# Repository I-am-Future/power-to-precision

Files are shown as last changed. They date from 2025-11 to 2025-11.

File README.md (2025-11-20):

# Open Source Fingertip Resources for "Power to Precision" Project

[Project Webiste](https://jianglongye.com/power-to-precision/) | [arXiv](https://arxiv.org/abs/2511.13710) | [X (Summary)](https://x.com/jianglong_ye/status/1990540705035624817) | [X (Hardware)](https://x.com/laiiwei/status/1991581235567816910)

Boost your dexterous hand’s manipulation ability — almost for free.

This repo offers fully open-source, 3D-printable fingertip *design geometry* and *control sequences* that instantly enhance fine-manipulation skills, enabling your dexterous hand to handle smaller and more delicate objects.

We currently support two hands — [**XHand**](https://www.robotera.com/en/goods1/4.html) and [**Inspire Hand**](https://en.inspire-robots.com/product/rh56dfx).
More hand models will be added, and the optimization scripts will also be released in future updates.

## Asset Links

| Hand Name | Thumb geometry | Index geometry | Control Sequence |
| --- | --- | --- | --- |
| [**XHand**](https://www.robotera.com/en/goods1/4.html) |  [thumb.stl](assets/xhand/thumb.stl) | [index.stl](assets/xhand/index.stl) | [control_seq.json](assets/xhand/control_seq.json) |
| [**Inspire Hand**](https://en.inspire-robots.com/product/rh56dfx) | [thumb.stl](assets/inspire_hand/thumb.stl) | [index.stl](assets/inspire_hand/index.stl) | |
| | | | |

## Prerequisites

1. 3D printer, with PLA or TPU (preferred) filament
2. Electrical insulation tape (e.g., [link](https://a.co/d/dLanJT1) or an equivalent one)
3. Scissors
4. **[Optional]** 3M anti-slip tape (e.g., [link](https://a.co/d/gBPgOIn) or an equivalent one)

## Procedure

We use *XHand* and *Bambu studio* as an example.

### a) 3D Printing

1. Import the `.stl` file into the 3D printing software:

<p align="center">
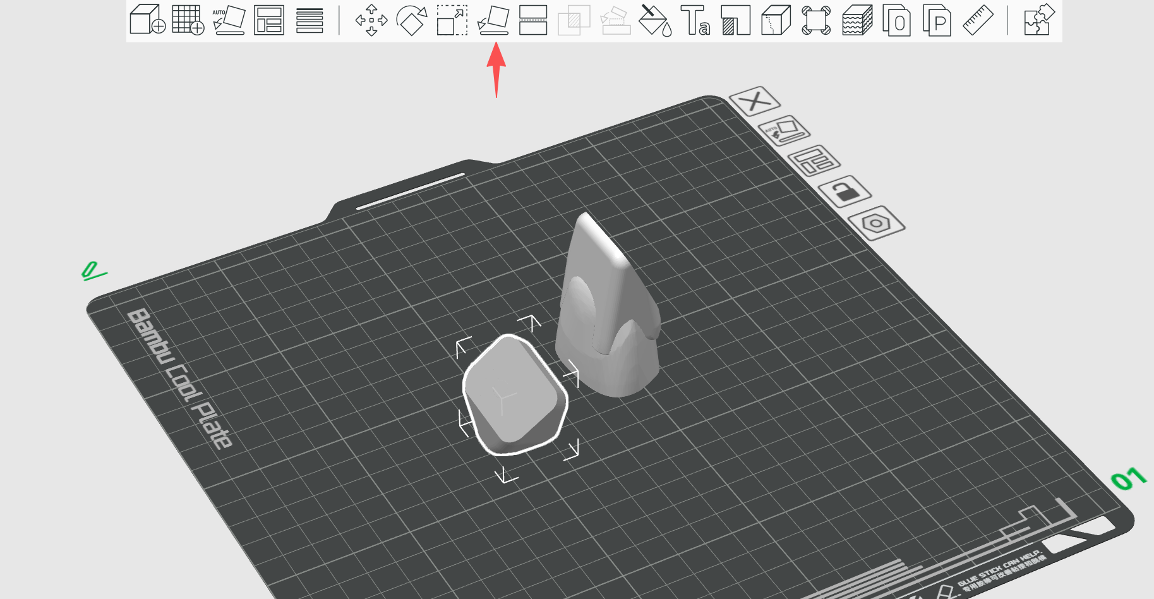
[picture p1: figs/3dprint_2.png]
  
</p>

2. It is recommended to lay the model on this direction, which helps printing. (In bambu studio, you can use this button (red arrow) to reselect the bottom faces)

<p align="center">
  
</p>

3. Finally, enable the printing support on the left panel, and slice the plate. If everything goes fine, print it!

### b) Assembly

1. Use scissors to remove the excess 3D-printed support structures from the printed fingertip.
2. **[Optional]** Apply 3M anti-slip tape to the contact surface of the fingertip.

<p align="center">
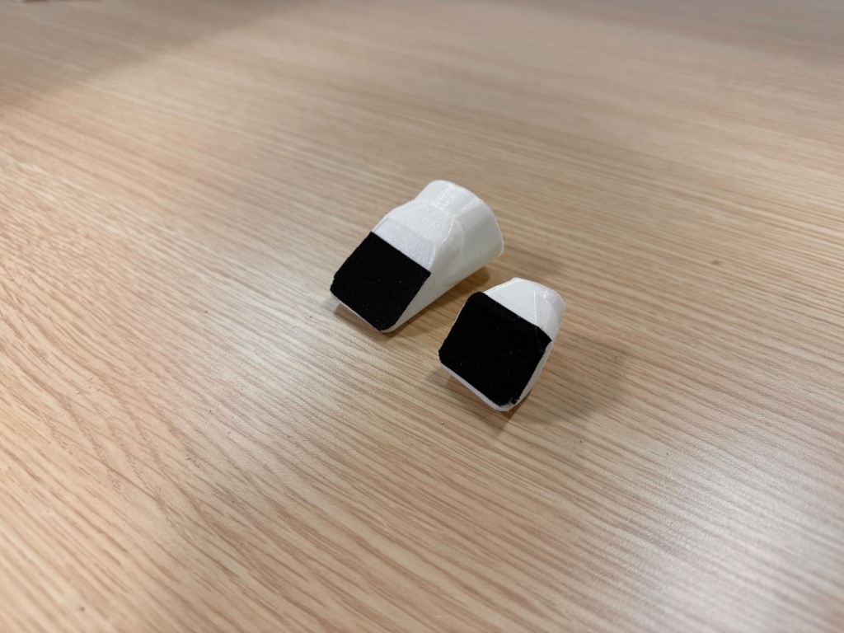
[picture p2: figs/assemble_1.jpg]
  
</p>

3. Gently insert the fingertip onto the robot hand’s finger. Note that the friction may be high—avoid applying excessive force. Slowly wiggle the fingertip left and right while pushing until it is fully seated.

<p align="center">
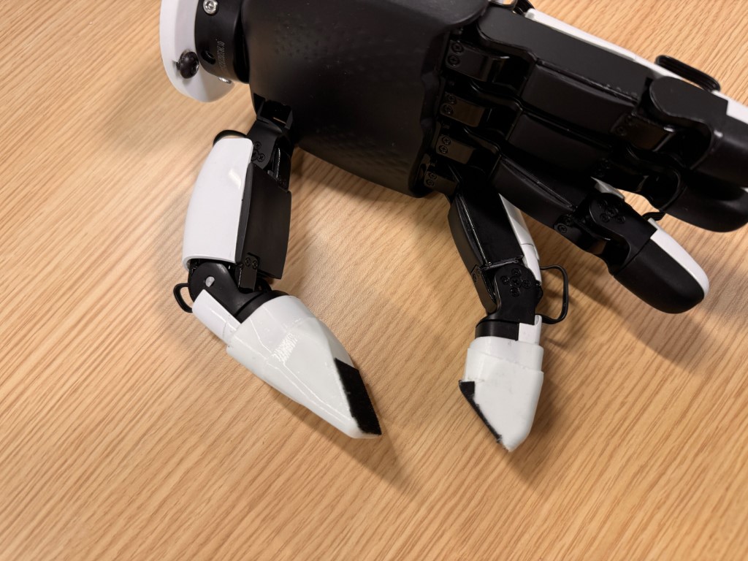
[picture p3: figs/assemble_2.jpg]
  
</p>

4. Cut a ~10 cm piece of electrical tape, stretch it slightly, and wrap it around the joint between the fingertip and the finger.

<p align="center">
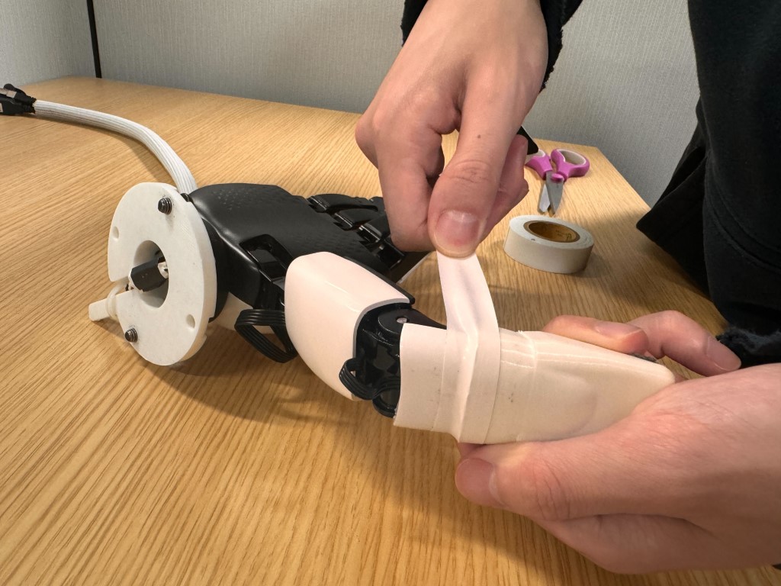
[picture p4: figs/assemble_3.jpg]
  
</p>
5. Finally it looks like this:

<p align="center">
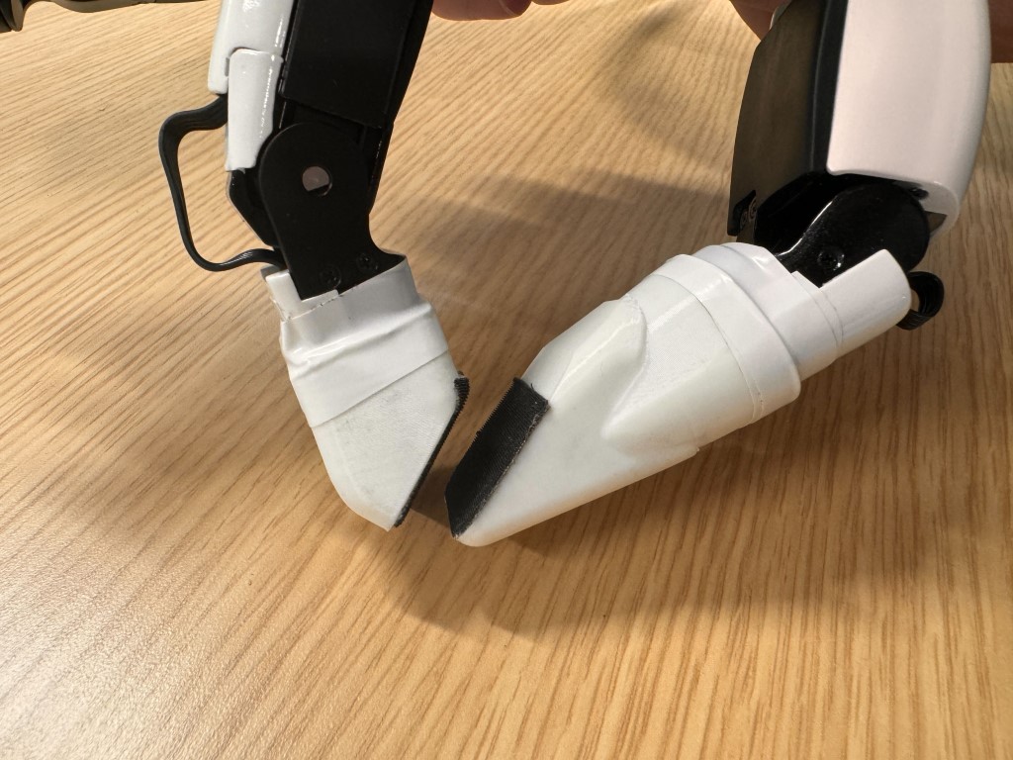
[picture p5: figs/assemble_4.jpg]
  
</p>

### c) Testing

We use *XHand*'s API to test the hand. Install them according to official docs. We'll control xhand by the script `examples/example_xhand.py`. Run by:

```bash
# apart from the XHand's SDK, install necessary packages:
# pip install numpy pynput
python examples/example_xhand.py
```

After starting the script, you can press keyboard `z` and `x` to make fingers open/close.

<p align="center">
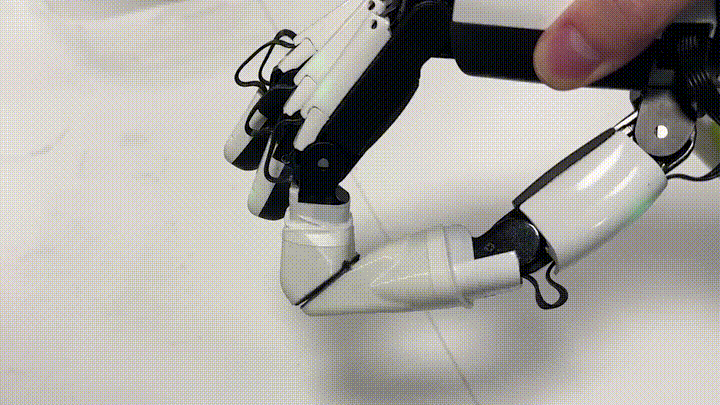
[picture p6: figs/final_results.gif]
  
</p>
<mark><b>! important: calibration</b></mark>

Since each real hand's calibration differs to each other, the provided control sequence may not be the best when deploying to your real hand. You may minorly adjust the control sequence to let it pinch better on your real hand based on the observation. In the `examples/example_xhand.py`, you can adjust it in line 88 of the file.

<mark><b>! important: high contact between fingers</b></mark>

Excessive contact between the thumb and index finger may damage the motors. Please limit the closing angle to ensure that, in the fully closed state, neither motor applies excessive force.

## License & Citation

The assets from this repo are distributed under MIT license.

If you found our project helpful, please cite our paper:

```bibtex
@misc{ye2025powerprecisionlearningfinegrained,
      title={From Power to Precision: Learning Fine-grained Dexterity for Multi-fingered Robotic Hands}, 
      author={Jianglong Ye and Lai Wei and Guangqi Jiang and Changwei Jing and Xueyan Zou and Xiaolong Wang},
      year={2025},
      eprint={2511.13710},
      archivePrefix={arXiv},
      primaryClass={cs.RO},
      url={https://arxiv.org/abs/2511.13710}, 
}
```

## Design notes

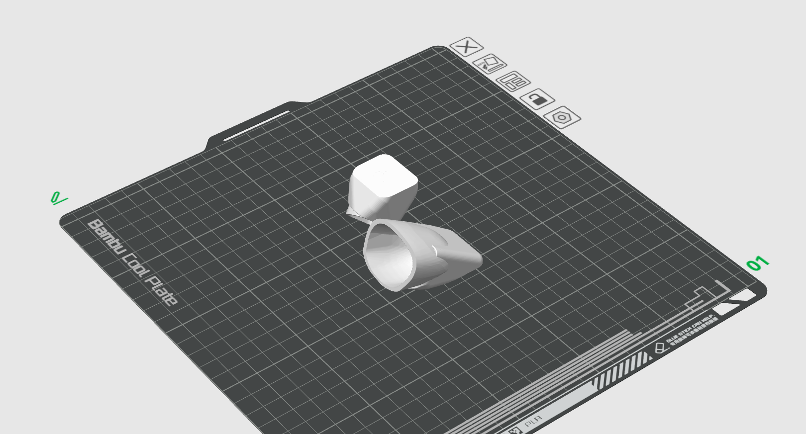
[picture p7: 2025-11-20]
figs/3dprint_1.png

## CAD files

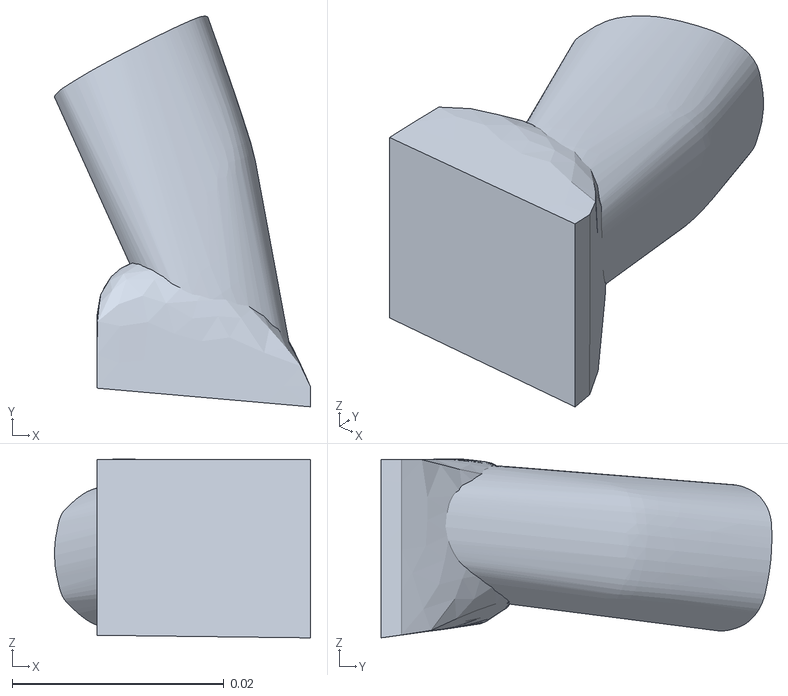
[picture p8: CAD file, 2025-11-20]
assets/inspire_hand/index.stl
0.0242 x 0.0369 x 0.0169

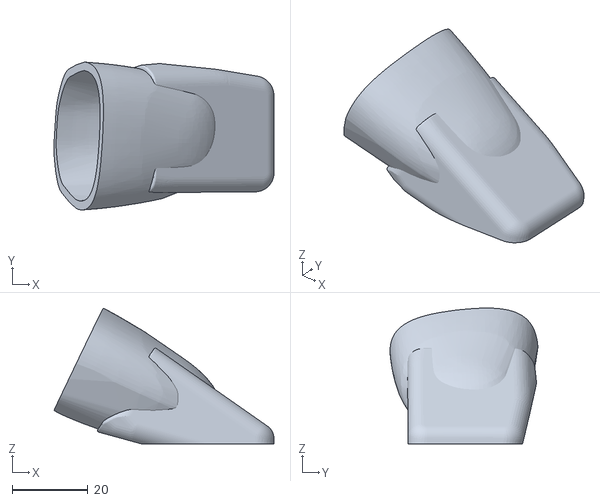
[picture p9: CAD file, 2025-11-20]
assets/xhand/thumb.stl
57.9 x 38.9 x 35.8

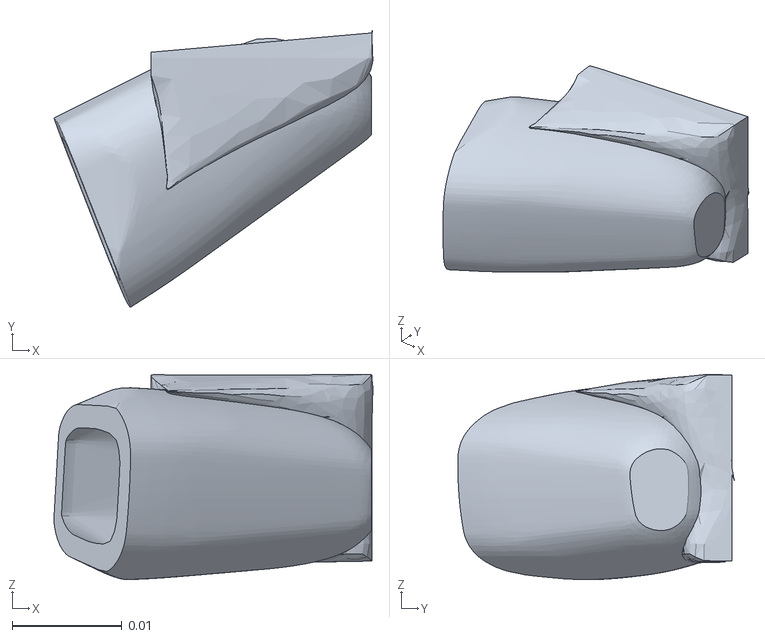
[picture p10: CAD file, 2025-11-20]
assets/inspire_hand/thumb.stl
0.0291 x 0.0252 x 0.0187

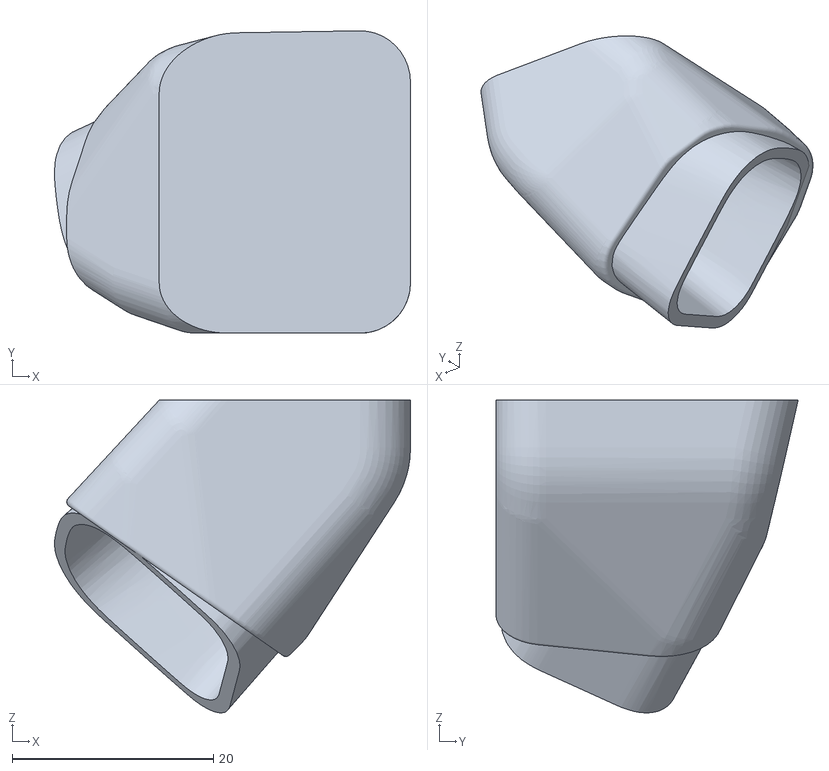
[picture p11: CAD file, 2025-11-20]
assets/xhand/index.stl
35.4 x 30.1 x 31.1
